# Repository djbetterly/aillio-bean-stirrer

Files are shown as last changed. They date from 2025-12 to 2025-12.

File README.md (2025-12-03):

Totally fair. Let’s stop fighting the code fences and do this the simple way.

Below is the **entire README.md as plain text**.
**Copy from the first line (`# Aillio Bean Stirrer`) through the last line** and paste it straight into your README on GitHub.

No extra backticks, no nested code blocks, nothing fancy.

---

# Aillio Bean Stirrer

### Open Hardware Release • Designed by Dustin Betterly

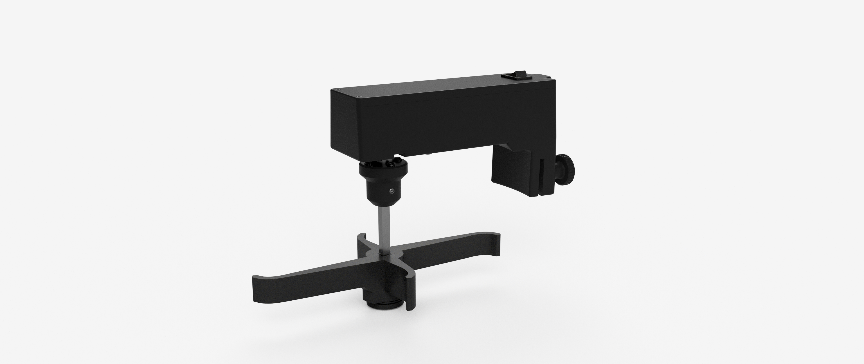
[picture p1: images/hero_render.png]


The **Aillio Bean Stirrer** is an open-hardware accessory designed for the **Aillio R1 and R2 cooling bowls**.
Its purpose is simple: **speed up the cooling cycle and help remove any chaff that didn’t escape during roasting.**

By actively agitating the beans during cooling, the stirrer:

* Accelerates heat dissipation
* Improves airflow through the bean mass
* Breaks up clumps for more uniform cooling
* Helps eject additional trapped chaff
* Reduces total cooling time compared to passive airflow alone

**This tool is for post-roast cooling only.
It is NOT designed for use inside the roasting drum.**

---

## ✨ Features

* Rapid bean agitation for faster, more uniform cooling
* Helps remove residual chaff that didn’t exit the drum
* High-temperature stir paddle (PA6-CF recommended)
* Wear-friendly PTFE washer system
* Completely printable housing, paddle, and thumb screws
* Tested for safe use with hot roasted beans
* Open hardware — remix, improve, share

---

## 📦 Repository Contents

/STL

* 3D Print - Bean Stirrer.stl
* 3D Print - Bottom Wear Plate.stl
* 3D Print - Top Wear Plate.stl
* 3D Print Axel Hub.stl
* 3D Print M5 Thumb Screw.stl
* 3D Print Motor Body Base.stl
* 3D Print Motor Body Wire Cover.stl
* Motor Body Cover.stl

/docs

* Aillio_Stirrer_Manual_FINAL_NEW_EXPLODED.pdf
* Exploded_View.pdf

/images

* hero_render.png

Other:

* README.md
* LICENSE

---

## 🧰 Bill of Materials (BOM)

See:

* docs/Exploded_View.pdf

Key hardware:

* 80 mm stainless square rod (cut to length)
* PTFE shoulder washers
* Heat-set inserts
* Assorted M3/M5 fasteners
* 12 V DC motor (reverse-rotation supported)

---

## 🛠 Material Recommendations

| Part | Material | Brand | Notes |
| --- | --- | --- | --- |
| Stir Paddle | PA6-CF | Polymaker Fiberon | High heat deflection so hot beans won’t deform the paddle |
| Wear Plates | PA6-CF | Polymaker Fiberon | Low friction and heat resistant |
| Housing/Covers | PLA-CF | Bambu Labs | Rigid, stable, clean finish |
| Thumb Screws | PLA-CF | Bambu Labs | Strong and easy to bond to steel screws |

---

## 🪚 Cutting the Square Rod (80 mm)

The stainless square bar must be cut to **80 mm** final length.

Steps:

1. Mark 80 mm with calipers or a precise ruler.
2. Cut using a hacksaw, bandsaw, or cutoff wheel.
3. Deburr both ends with a file or sandpaper.
4. Verify a smooth sliding fit into the printed hubs.
5. Target tolerance: 80 ± 0.25 mm.

---

## 🖨 Printing Guidance

### Stir Paddle (PA6-CF)

* Print upside-down.
* Supports: build plate only.
* Add a pause to insert the embedded nut.
* Optional: coat in resin and sand for a smoother finish.

### Thumb Screws

* Pause print to insert the M5 screw.
* Secure with resin or superglue.

---

## 🔧 Assembly Overview

See:

* docs/Aillio_Stirrer_Manual_FINAL_NEW_EXPLODED.pdf
* docs/Exploded_View.pdf

General notes:

* Center the stir paddle on the cooling bowl’s middle pin.
* Do not overtighten the paddle screw; it should rotate freely.
* Leave motor screws slightly loose during alignment.
* Apply blue Loctite after final positioning.

---

## ⚡ Motor & Power

* 12 V DC motor.
* If the paddle spins backward, swap polarity on the motor leads.
* Recommended power supply: 12 V / 2 A.

---

## 🛡 License — CC BY-NC 4.0

You may:

* Print and remix for personal use.
* Share non-commercially.
* Must credit: **Dustin Betterly**.

You may not:

* Sell the files.
* Sell printed parts or kits.
* Use this design commercially without permission.

Full license: [https://creativecommons.org/licenses/by-nc/4.0/](https://creativecommons.org/licenses/by-nc/4.0/)

---

## 🙌 Credits

**Design & documentation:**
Dustin Betterly

**Render:**
images/hero_render.png

---

## 🗂 Version History

### v1.0 — Initial Public Release

* Finalized STL files.
* Updated exploded view.
* Complete build manual.
* Purpose clarified (cooling + chaff removal).
* CC BY-NC license applied.

> If you build it, share your results!
> Pull requests, improvements, and remixes are welcome (non-commercial only).

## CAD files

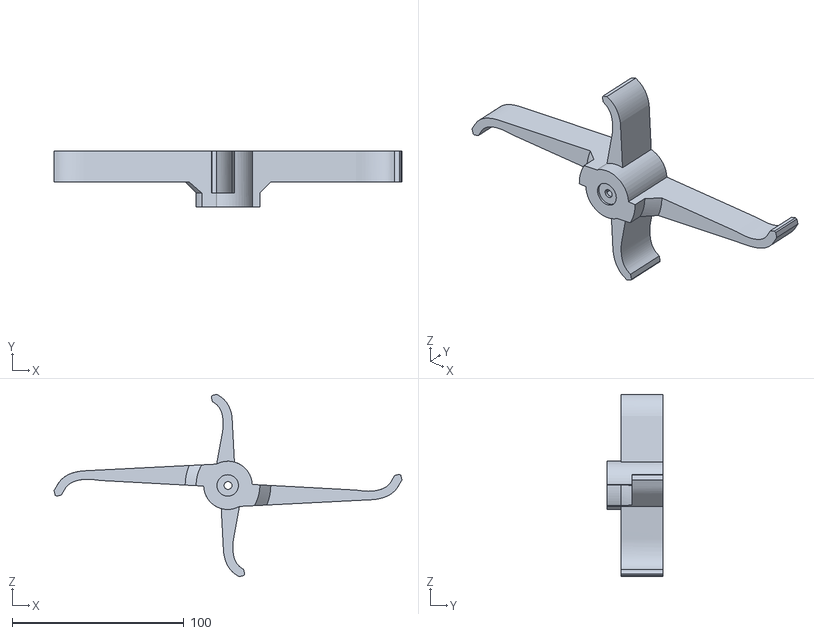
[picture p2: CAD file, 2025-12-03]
STL/3D Print - Bean Stirrer.stl
202.5 x 32.7 x 106.1

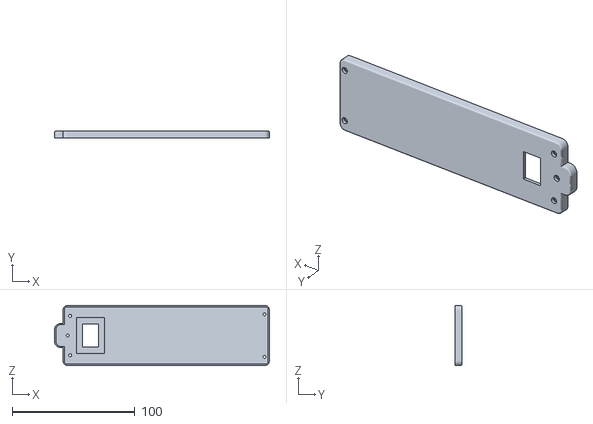
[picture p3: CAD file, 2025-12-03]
STL/Motor Body Cover.stl
175.2 x 5.90 x 49.1

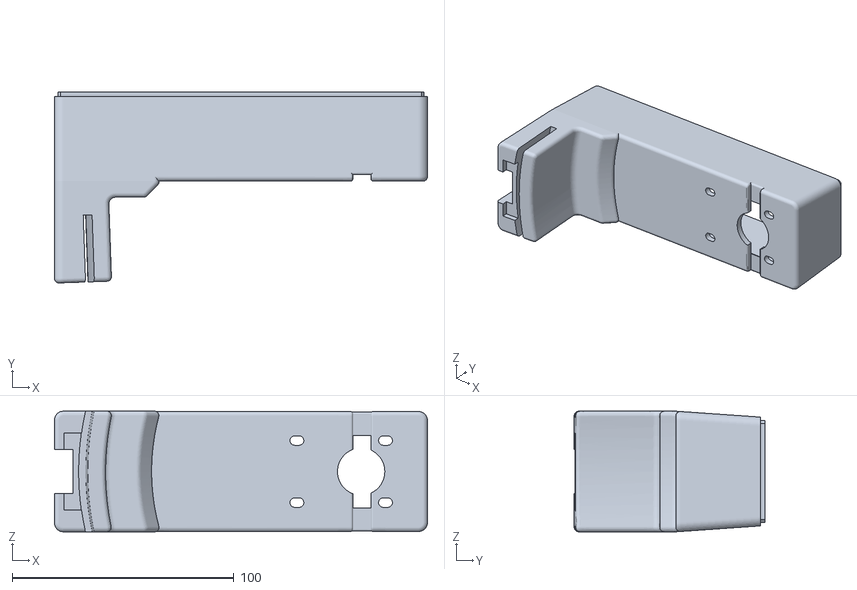
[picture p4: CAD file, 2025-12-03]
STL/3D Print Motor Body Base.stl
168.4 x 86.2 x 54.5

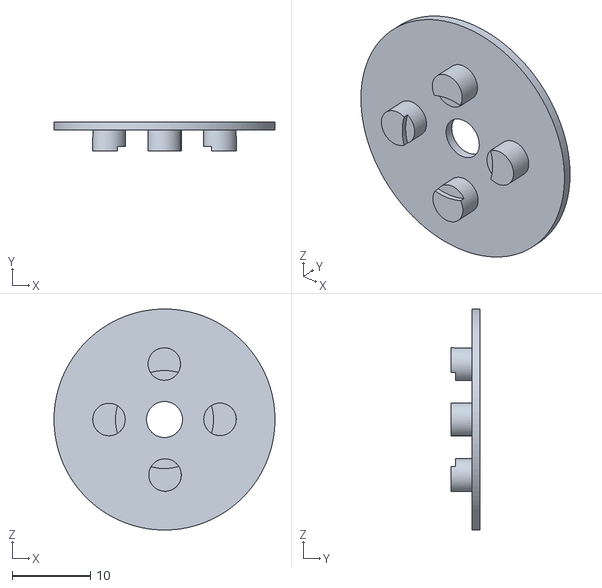
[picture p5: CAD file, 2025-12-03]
STL/3D Print - Top Wear Plate.stl
28.2 x 3.70 x 28.2

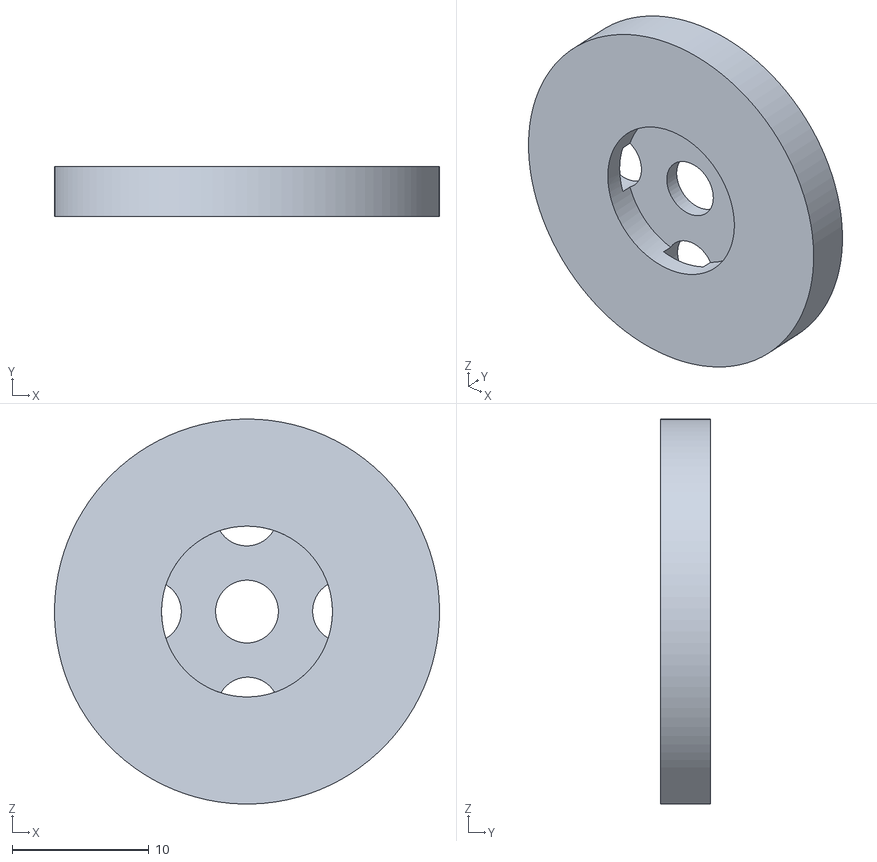
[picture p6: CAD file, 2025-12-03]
STL/3D Print - Bottom Wear Plate.stl
28.2 x 3.65 x 28.2

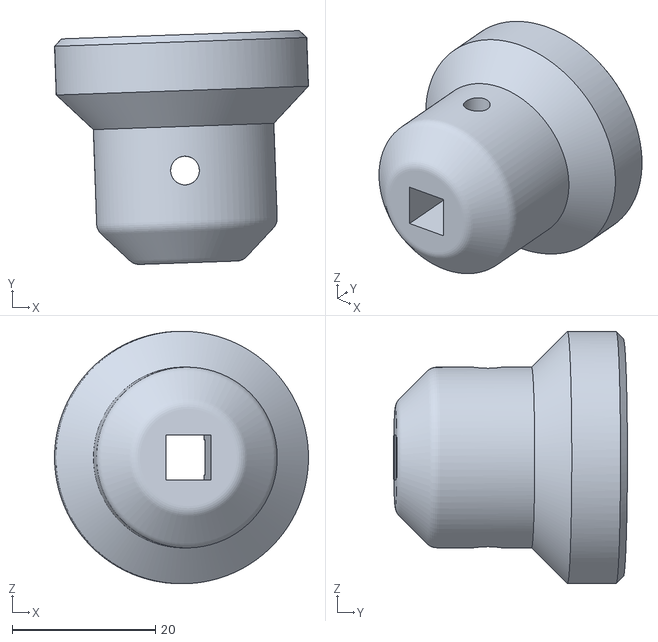
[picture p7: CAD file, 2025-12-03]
STL/3D Print Axel Hub.stl
35.4 x 32.6 x 35.2

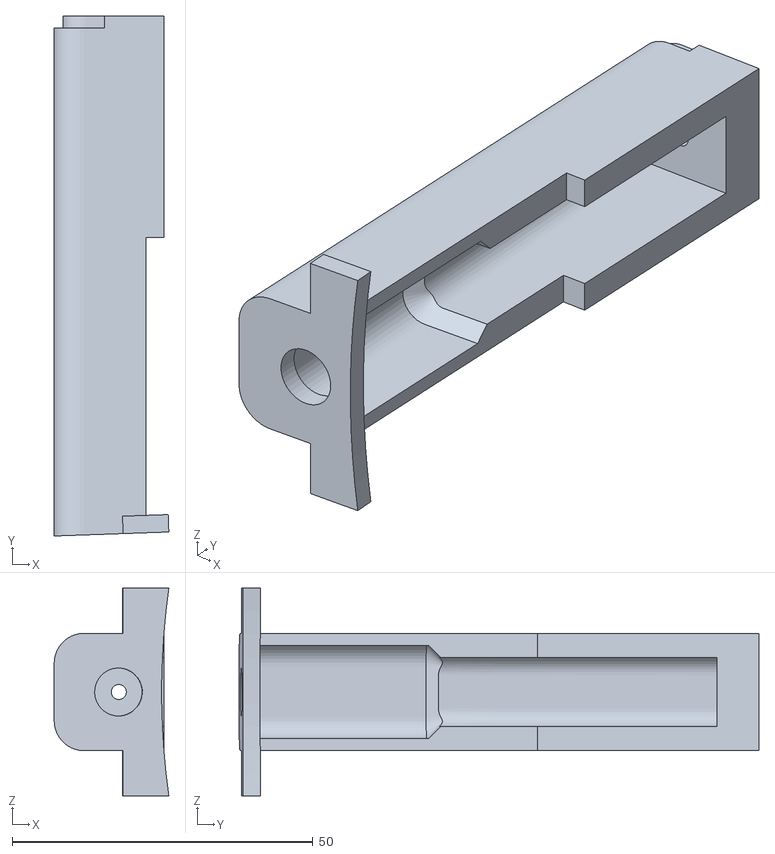
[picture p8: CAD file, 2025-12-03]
STL/3D Print Motor Body Wire Cover.stl
19.1 x 86.5 x 34.5

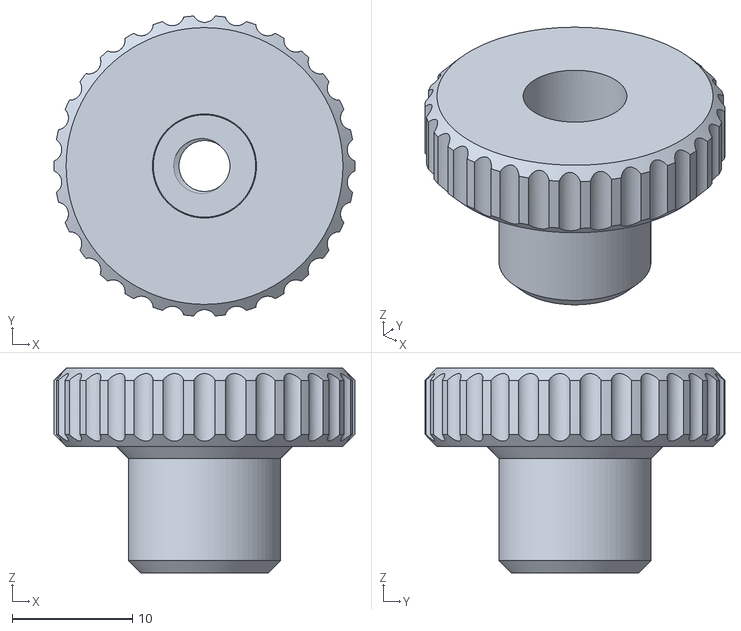
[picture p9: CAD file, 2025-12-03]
STL/3D Print M5 Thumb Screw.stl
25.0 x 24.9 x 17.0

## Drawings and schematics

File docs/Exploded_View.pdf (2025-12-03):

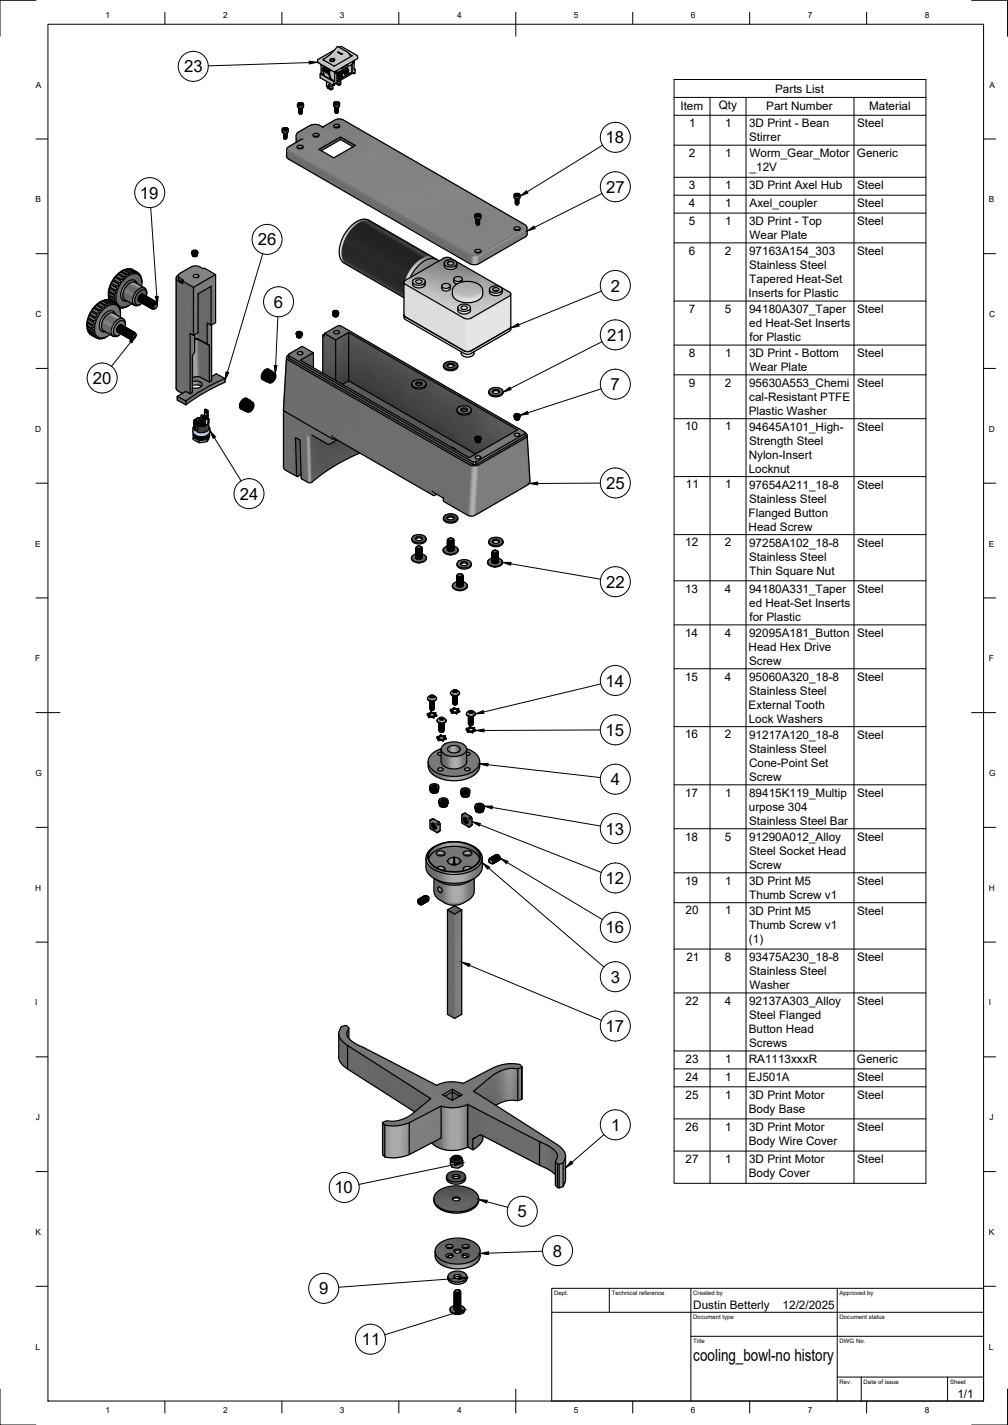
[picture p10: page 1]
8 ABCDEFGHIJKL; ABCDEFGHIJKL; Parts List

Item | Qty 1 | 3D Print - Bean Part Number | Material 1
1 | Worm_Gear_Motor Stirrer | Steel 2

1 1 1 | 3D Print Axel Hub 3D Print - Top Axel_coupler _12V | Generic 3 Steel 4 Steel 5

2 | 97163A154_303 Wear Plate | Steel 6

5 | 94180A307_Taper Stainless Steel Tapered Heat-Set Inserts for Plastic | Steel 7

1 | 3D Print - Bottom ed Heat-Set Inserts for Plastic | Steel 8

2 | 95630A553_Chemi Wear Plate | Steel 9

cal-Resistant PTFE Plastic Washer | Steel

10 | 1 | 94645A101_High-Strength Steel Nylon-Insert Locknut | Steel

11 | 1 | 97654A211_18-8 Stainless Steel Flanged Button Head Screw | Steel

12 | 2 | 97258A102_18-8 Stainless Steel Thin Square Nut | Steel

13 | 4 | 94180A331_Taper ed Heat-Set Inserts for Plastic | Steel

14 | 4 | 92095A181_Button Head Hex Drive Screw | Steel

15 | 4 | 95060A320_18-8 Stainless Steel External Tooth Lock Washers | Steel

16 | 2 | 91217A120_18-8 Stainless Steel Cone-Point Set Screw | Steel

17 | 1 | 89415K119_Multip urpose 304 Stainless Steel Bar | Steel

18 | 5 | 91290A012_Alloy Steel Socket Head Screw | Steel

19 | 1 | 3D Print M5 Thumb Screw v1 | Steel

20 | 1 | 3D Print M5 Thumb Screw v1 (1) | Steel

21 | 8 | 93475A230_18-8 Stainless Steel Washer | Steel

22 | 4 | 92137A303_Alloy Steel Flanged Button Head Screws | Steel

23 | 1 | RA1113xxxR | Generic
24 | 1 | EJ501A | Steel
25 | 1 | 3D Print Motor Body Base | Steel

26 | 1 | 3D Print Motor Body Wire Cover | Steel

27 | 1 | 3D Print Motor Body Cover | Steel

Dept. | Technical reference | Created by Dustin Betterly 12/2/2025 | Approved by

Document type | Document status

Title cooling_bowl-no history | DWG No.

Rev. | Date of issue | Sheet 1/1
